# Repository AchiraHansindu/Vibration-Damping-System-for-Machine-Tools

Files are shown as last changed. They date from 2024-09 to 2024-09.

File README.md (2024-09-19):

# **Vibration Damping System for Machine Tools**

## Overview
This repository contains the design and implementation details of a Vibration Damping System developed for machine tools. The system is designed to significantly reduce mechanical vibrations, which can degrade performance and increase wear and tear on machinery.

## Project Scope

This project is done as a partial fulfillment for EN2160: Electronic Design Realization module in the Semester 4 curriculum in the Department of Electronic and Telecommunication Engineering at University of Moratuwa, Sri Lanka.

This project was aimed to design and develop an industry level solution. Accordingly, a hardware-software co-solution is developed including PCB, Enclosure, Software, and Firmware.

## Components
- **Data Acquisition System:** Utilizes accelerometers to measure vibrations and a microcontroller to process data.
- **Vibration Analysis Software:** MATLAB scripts and an app designed for processing and analyzing vibration data.
- **Spring and Damper System:** Custom designed spring and damper system to the specific vibration characteristics of the machinery.

<div align="center">
    Data Acquisition System
    <br>
    <em>Data Acquisition System</em>
</div>

<div align="center">
    Data Acquisition System
    <br>
    <em>Custom Built Shock Absorber</em>
</div>

## Features
- **Real-time Vibration Monitoring:** Leverages a MPU6050 accelerometer to monitor vibrations in real time.
- **FFT Analysis:** Implements Fast Fourier Transform (FFT) for detailed frequency analysis to calculate the desing parameters for the shock absorber system.
- **Shock Absorber Efficiency Measurement:** Compares vibration data before and after shock absorber implementation to evaluate efficiency.

## PCB Design
- **Tools & Software:** Designed with Altium Designer, our 2-layer PCB features the ATmega328P-AU microcontroller and CH340C Serial UART IC, ensuring robust performance and reliable communication.
- **Design Philosophy:** Special attention has been given to the routing of power lines to reduce voltage drops and ensure signal integrity.

<div align="center">
    Bare PCB
    <br>
    <em>Bare PCB</em>
</div>

<div align="center">
    Soldered PCB
    <br>
    <em>Soldered PCB</em>
</div>

PCB design files and schematics can be found [here](https://github.com/AchiraHansindu/Vibration-Damping-System-for-Machine-Tools/tree/main/PCB%20Files).

## Firmware Design
- **Microcontroller Programming:** The microcontroller in programmed in C++, using register level programming such as IO port manipulation, UART and I2C communication, sampling accelerometer reading with given sampling frequency.

The code can be found [here](https://github.com/AchiraHansindu/Vibration-Damping-System-for-Machine-Tools/tree/main/Microcontroller%20AVR%20code).

## Enclosure Design
- Comprises two parts; the Main Controller Unit and the Accelerometer Holding Part, both designed in SOLIDWORKS and produced via 3D printing.

<div align="center">
    Main Controller Unit
    <br>
    <em>Main Controller Unit</em>
</div>

<div align="center">
    Accelerometer Holding Part
    <br>
    <em>Accelerometer Holding Part</em>
</div>

Enclosure design files can be found [here](https://github.com/AchiraHansindu/Vibration-Damping-System-for-Machine-Tools/tree/main/Enclosure%20Design-SolidWorks).

## Software Design

### Front-End Software: UI for Data Acquisition System

The Front-End Software for the Vibration Data Acquisition System streamlines interaction between the DAQ device and the user. Developed using Python and PyQt5, the application features a user-friendly graphical interface for starting, stopping, and saving vibration data.

#### Key Features:
- **Initial Setup:** Users begin at a launch screen and proceed to select communication settings like COM port and baud rate.
- **Data Collection Controls:** Provides options to start and stop the recording and to save the captured data with user-defined settings.
- **Efficient Data Management:** After collection, data can be saved through a dialog that captures file details and confirms the save location.

This intuitive interface supports efficient data handling and simplifies the user's interaction with the system.

<div align="center">
    Screen for selecting the available COM port and baud rate.
    <br>
    <em>Screen for selecting the available COM port and baud rate.</em>
</div>

<div align="center">
    Screen for controlling data collection.
    <br>
    <em>Screen for controlling data collection.</em>
</div>

The code can be found [here](https://github.com/AchiraHansindu/Vibration-Damping-System-for-Machine-Tools/tree/main/UI%20for%20Data%20Acquisition%20System).

### MATLAB Application for Data Analysis

The MATLAB Application for Data Analysis enhances the vibration-damping system by providing detailed processing and visualization of vibrational data collected from machine tools. Developed to support engineers and researchers, this application includes multiple analytical tools and visualization methods.

#### Key Features:
- **Data Visualization:** Plots acceleration data along the X, Y, and Z axes, directly from CSV files generated by the DAQ system, providing immediate visual insight into the vibrational characteristics of the machine tools.
- **Frequency Spectrum Analysis:** Employs Fast Fourier Transform (FFT) to convert time-domain data into frequency-domain data, identifying dominant frequencies that are crucial for the subsequent design of effective vibration-damping solutions.
- **System Parameters Calculation:** Automatically extracts essential parameters such as natural frequency and damping ratio from FFT results. Users can further input mechanical properties like mass and piston diameter to compute critical damping characteristics, aiding in the precise design of the shock absorber.
- **Performance Comparison:** Facilitates loading and comparing vibration data before and after the implementation of damping solutions. 

This MATLAB application is a pivotal part of the software design, bridging data acquisition with actionable analysis, thus supporting both the design and evaluation stages of the vibration-damping system.

<div align="center">
    Window showing FFT for X, Y, and Z axes.
    <br>
    <em>Window showing FFT for X, Y, and Z axes.</em>
</div>

<div align="center">
    System parameters calculation window.
    <br>
    <em>System parameters calculation window.</em>
</div>

The code can be found [here](https://github.com/AchiraHansindu/Vibration-Damping-System-for-Machine-Tools/tree/main/MATLAB%20Application%20for%20Data%20Analysis).

## System Integration

The following images show some steps of system integration including wiring, assembling.

<div align="center">
    
    <br>
    <em></em>
</div>

<div align="center">
    
    <br>
    <em></em>
</div>

## Demonstration

To visually demonstrate the effectiveness of the Vibration Damping System, we have included videos and FFT analysis both before and after the implementation of the shock absorber.

### Videos

1. **Before Shock Absorber Implementation:**
   - This video showcases the system operating without the shock absorber, highlighting the initial vibration levels and rotation.

   https://github.com/user-attachments/assets/478091ad-a99a-40b5-b485-41ef5b800e22

2. **After Shock Absorber Implementation:**
   - This video demonstrates the system with the shock absorber installed, showing a significant reduction in vibrations and rotation.

   https://github.com/user-attachments/assets/1908306d-d9c9-451e-9375-d828b028359c

### FFT Analysis

- **FFT Before Implementation:**
  - The FFT analysis before implementing the shock absorber shows higher amplitude peaks at natural frequencies.

  <div align="center">
    FFT before implementing the damper
    <br>
    <em>FFT before implementing the damper</em>
</div>

- **FFT After Implementation:**
  - After the shock absorber installation, the FFT analysis displays a noticeable reduction in peak amplitudes.

  <div align="center">
    FFT after implementing the damper
    <br>
    <em>FFT after implementing the damper</em>
</div>

This side-by-side comparison not only validates the design but also provides concrete evidence of the system's performance improvements.

## Documents Related to the Project

For a deeper understanding of our Vibration Damping System, detailed documentation is available. Below are the links to various documents that cover all aspects of the project:

1. [Design Methodology Document](https://github.com/AchiraHansindu/Vibration-Damping-System-for-Machine-Tools/blob/main/Project%20Documents/Design_Methodology_Document_Vibration_Damping%20System_for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) 
2. [Comprehensive Design Document](https://github.com/AchiraHansindu/Vibration-Damping-System-for-Machine-Tools/blob/main/Project%20Documents/Design_Document_Vibration_Damping%20System_for_Machine_Too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) 

Feel free to explore these resources to gain a comprehensive understanding of the project's scope and execution.

## Team Members

- [Achira Hansindu](https://github.com/AchiraHansindu)
- [Sandaru Liyanaarachchi](https://github.com/Sandaru-Liyanaarachchi)

## Contributions

Contributions are welcome!

- **Bug Fixes:** If you find any bugs or issues, feel free to create an issue or submit a pull request.
-**Feature Enhancements:** If you have ideas for new features or improvements, don't hesitate to share them.

Feel free to reach out with any questions or suggestions!

## License

This project is licensed under the [MIT License](https://github.com/AchiraHansindu/Vibration-Damping-System-for-Machine-Tools/blob/main/LICENSE).

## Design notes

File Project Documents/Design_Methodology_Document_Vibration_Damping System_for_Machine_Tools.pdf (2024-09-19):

# Department of Electronic and Telecommunication Engineering University of Moratuwa

# EN2160- Electronic Design Realization

# Design Methodology Document


# Vibration Damping System for Machine Tools

# Group K (29)

210204R Hansindu K.A.A.

210341H Liyanaarachchi L.A.S.

## Contents

1 Introduction | 5
2 Review Progress | 6
2.1.2 | Vibration Damping Control of Robot Arm Intended for Service
2.1.5 | Hybrid Damper with Tunable Particle Impact Damping and
3 Identification Of Stake Holders | 12
4 Observe Users | 15

1

5 Need List | 19
6 Stimulate Ideas | 21
7 Conceptual Design | 23

2

8 Evaluation of Conceptual Design | 33
9 Schematic Design | 37
10 PCB Design | 44
11 SolidWorks Design | 47

3

References | 56

4

## 1 Introduction

The Design Methodology Document for the Vibration Damping System for Machine Tools was created following the Cambridge EDC Inclusive Design Methodology. This document provides a comprehensive overview of the project’s development, focusing on designing a data acquisition system for vibrational data and a spring and damper system to enhance the performance and reliability of machine tools. The primary objectives of this project are to minimize vibrations that can affect the precision and longevity of machine tools and to provide a robust data acquisition framework for continuous monitoring and analysis.
The methodology employed ensures that the design process is thorough, inclusive, and user-centered, incorporating feedback from a wide range of stakeholders including engineers, developers, manufacturers, and end-users. This approach not only improves the design’s functionality but also ensures its practical applicability in real-world scenarios.
Key aspects of the design process include:
- Review of Existing Solutions: Analyzing current industry practices and academic research to understand the state-of-the-art in vibration damping systems.
- Stakeholder Engagement: Identifying and involving key stakeholders to gather requirements and ensure the design meets their needs.
- User Observation and Feedback: Studying how different users interact with machine tools and identifying their needs and pain points.
- Concept Development: Generating multiple design concepts and evaluating them against established criteria to select the most effective solution.
- Detailed Design and Prototyping: Creating detailed schematics and prototypes, followed by rigorous testing to validate the design.

The document is structured to provide a clear and detailed account of each phase of the project, ensuring transparency and facilitating future enhancements. This systematic and inclusive approach ensures the development of a reliable, efficient, and user-friendly vibration damping system that can significantly improve the operational efficiency and precision of machine tools.

5

## 2 Review Progress

A thorough analysis of the current advancements in vibration-damping systems for machine tools was conducted, drawing insights from industry practices, academic research, and existing commercial solutions. This review provided a solid foundation for our project’s objectives and methodology.

### 2.1 Academic Research

Research papers highlight the importance of accurately identifying the natural frequencies of machine tools to design effective damping systems. Techniques using accelerometers and signal processing algorithms have been widely studied.

### 2.1.1 Analysis of Vibration Damping in Machine Tools

Description: This study provides a detailed analysis of energy dissipation mechanisms in machine tools, incorporating frictional forces, control loops, and modal damping into numerical models.

Key Findings: Highlights the significance of integrating these mechanisms for accurate dynamic behavior prediction, crucial for optimizing material removal and minimizing oscillations.

Reference: Bianchi, G. et al., 2014. ”Analysis of Vibration Damping in Machine Tools,” Procedia CIRP.

Link: Analysis of Vibration Damping in Machine Tools (https://www.researchgate.net/publication/275230904_Analysis_of_Vibration_Damping_in_Machine_Tools)

### 2.1.2 Vibration Damping Control of Robot Arm Intended for Service

Application in Human Environment

Description: This study investigates the vibration-damping control of
an anthropomorphic robot arm designed for service applications, focusing
on improving safety and performance during physical interactions with humans and the environment.

Key Findings: The research demonstrates that by using torque measurement in each joint and tactile area recognition, the proposed vibration damping control significantly reduces oscillations in heavily loaded joints. This is achieved through acceleration signal feedback and a lead controller, enhancing the robot’s smooth continuous motion and ensuring safer interactions with humans.
Reference: Tsetserukou, D., Kawakami, N., & Tachi, S. (2008). ”Vibration Damping Control of Robot Arm Intended for Service Application in Human Environment,” 2008 8th IEEE-RAS International Conference on Humanoid Robots (Humanoids 2008). DOI: 10.1109/ICHR.2008.4756002

Link: Vibration damping control of robot arm intended for service application in the human environment (https://www.researchgate.net/publication/224373517_Vibration_damping_control_of_robot_arm_intended_for_service_application_in_human_environment)

6

### 2.1.3 Active Vibration Control for a CNC Milling Machine

Description: Explores adaptive vibration control methods for CNC milling machines, focusing on improving surface finish, reducing tool wear, and compensating for structural vibrations under high-speed machining conditions.

Key Findings: The active vibration control system uses sensors and adaptive controllers to measure and mitigate vibrations, resulting in improved machining accuracy and surface quality. The study demonstrated significant vibration reduction and enhanced stability in CNC milling operations.

Reference: Ford, D.G., Myers, A., Haase, F., Lockwood, S., & Longstaff, A.P. (2013). ”Active Vibration Control for a CNC Milling Machine,” Proceedings of the Institution of Mechanical Engineers, Part C: Journal of Mechanical Engineering Science. DOI: 10.1177/0954406213484224

Link: Active vibration control for a CNC milling machine (https://www.academia.edu/56290445/Active_vibration_control_for_a_CNC_milling_machine)

### 2.1.4 Active Vibration Damping with Magnetic Actuators

Description: Explores the use of magnetic actuators for active damping of machine tools, focusing on reducing chatter and improving machining stability.

Key Findings: Effective in suppressing vibrations, enhancing tool performance, increasing dynamic stiffness, and significantly improving chatterfree material removal rates.

Reference: Chen, F., Hanifzadegan, M., Altintas, Y., & Lu, X. (2015). ”Active Damping of Boring Bar Vibration With a Magnetic Actuator,” IEEE/ASME Transactions on Mechatronics, 20(6), 1-12. DOI:

Link: Active Damping of Boring Bar Vibration With a Magnetic Actuator (https://www.researchgate.net/publication/276383735_Active_Damping_of_Boring_Bar_Vibration_With_a_Magnetic_Actuator)

### 2.1.5 Hybrid Damper with Tunable Particle Impact Damping and Coulomb

Friction

Description: This study examines a hybrid damper combining a particle impact damper (PID) and a Coulomb friction damper (FD). It highlights the advantages of both damping technologies, aiming to improve the damping capacity of the PID and FD. The damper is theoretically modeled and experimentally tested on a single-degree-of-freedom (SDOF) structure.

Key Findings: The proposed hybrid damper effectively reduces the maximum vibration amplitude by 66% and 43% compared to using the FD and PID only, respectively. It is also effective over a wide range of excitation

7

frequencies and does not require an optimally tuned natural frequency and damping, unlike traditional tuned mass dampers (TMDs).

Reference: Akbar, M.A., Wong, W.-O., & Rustighi, E. (2023). ”A Hybrid Damper with Tunable Particle Impact Damping and Coulomb Friction,” Machines, 11(5), 545. DOI: 10.3390/machines11050545

Link: Hybrid Damper with Tunable Particle Impact Damping and Coulomb Friction (https://www.mdpi.com/2075-1702/11/5/545)

### 2.2 Industry Developments

Industry advancements in vibration-damping systems for machine tools have led to the development of both active and passive solutions designed to enhance machining precision and tool life. These products demonstrate significant advancements in reducing vibrations, thereby enhancing machining performance and tool longevity.

### 2.2.1 Sandvik Coromant - Silent Tools™ Turning Adapters

Description: The Silent Tools™ turning adapters by Sandvik Coromant feature an advanced internal damping mechanism designed to reduce vibrations during machining operations with long overhangs. The damping unit consists of a heavy mass supported by rubber spring elements and an oil-filled cavity, which enhances the damping effect.

Key Features: Enhanced damping mechanism, improved surface finish, increased tool life, and efficient performance in long overhang operations.

Applications: Ideal for internal turning operations with extended tool lengths.
Link: Silent Tools™ for turning (https://www.sandvik.coromant.com/en-us/tools/turning-tools/internal-turning-tools/silent-tools-turning)

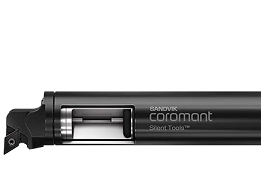
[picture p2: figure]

Figure 1: Silent Tools™ cylindrical turning adaptors

8

### 2.2.2 Big Daishowa - Smart Damper

Description: The Smart Damper by Big Daishowa integrates a damping mechanism close to the cutting edge, which significantly reduces vibrations in deep boring applications. The system is designed for both fine and rough boring operations.

Key Features: High efficiency in deep hole finish boring, improved surface finish, and extended tool life.

Applications: Ideal for boring operations requiring high precision and minimal vibration.

Link: Damping Tools (https://www.bigkaiser.eu/en/products/damping-tools.html)

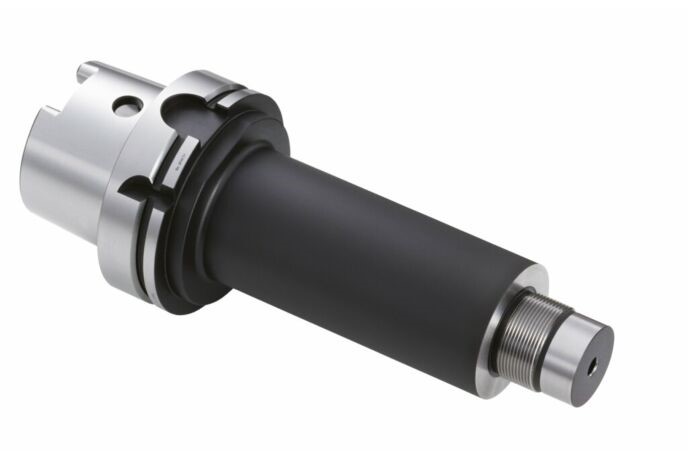
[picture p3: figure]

Figure 2: Smart Damper Basic Holders for Mills HSK-A

### 2.2.3 Seco Tools - Steadyline® Vibration Damping System

Description: The Steadyline® system by Seco Tools is designed for high rigidity and stability during extreme cutting conditions. It employs a dynamic passive damping system within the holder body, where a damping mass counteracts flexural vibrations.

Key Features: Available in various bar sizes (6xD, 8xD, 10xD), features coolant supply channels, and quick mounting and setting procedures.

Applications: Suitable for roughing and finishing operations with long overhang tools, providing high metal-removal rates and smooth surface finishes.
Link: Seco expands Steadyline® vibration damping system with boring bars (https://www.secotools.com/article/20850)

9

Figure 3: Seco expands Steadyline® vibration damping system with boring bars

### 2.2.4 Makino - ADVANTiGE Active Damping System

Description: The ADVANTiGE system by Makino adjusts frictional forces based on low-frequency vibration sensing to avoid chatter and cutter damage in real-time. This active damping system significantly enhances machining performance by enabling deeper cuts and higher metal-removal rates.

Key Features: Real-time vibration suppression, reduced tool wear, and improved machining accuracy.

Applications: Particularly effective in titanium machining and other high-stress cutting operations.

Link: Makino - ADVANTiGE Active Damping System (https://www.timachining.com/)

### 2.3 Summary of Findings

- Real-Time Adaptability: Active systems using sensors and control algorithms are highly effective in dynamically adjusting to vibrations, offering significant improvements in machining accuracy and tool longevity.
- Hybrid Solutions: Combining different damping mechanisms (e.g., particle impact and spring-damper systems) provides a versatile solution that can address a broader frequency range.
- Cost-Effectiveness: While active systems offer precise control, passive systems are more cost-effective and easier to implement, making them suitable for smaller workshops with budget constraints.

### 2.4 Progress

Upon receiving approval for the project, we began by planning the architecture of the Vibration Damping System (VDS) for machine tools, which features two primary components: the damping mechanism and the control module. The damping mechanism is designed to reduce vibrations passively. The control module serves as the command center, monitoring vibration levels.
The initial stage of the project focuses on designing and simulating the circuit schematics and mechanical layouts to ensure the VDS will achieve its targeted goals. Significant progress has been made in drafting the schematics for both the damping

10 mechanism and control module circuits. While the design of the control module is advancing smoothly, we have encountered challenges with the damping mechanism due to the need for precise tuning and component selection to maximize efficiency and minimize space requirements.
To overcome these obstacles, we are continuously reviewing and refining our designs. This involves experimenting with various strategies, such as exploring alternative components, adjusting layout configurations, and employing advanced signal processing algorithms for vibration detection and control. We are also integrating feedback from experts and conducting peer reviews to address potential issues proactively.
Throughout the design phase, we regularly review our progress to ensure alignment with project timelines and goals. This iterative process allows us to make necessary adjustments and improvements to the schematics. Once the circuit designs are complete and validated through rigorous testing, we will transition to implementing the circuits on prototype boards. These prototypes will undergo comprehensive laboratory testing to ensure they meet performance, safety, and reliability standards. Successful validation of the prototypes will pave the way for developing printed circuit boards (PCBs) using surface-mounted electronic components, enhancing the compactness and suitability of the system for industrial applications. Our ongoing review process includes testing various use-case scenarios and monitoring the interaction between the VDS components to ensure optimal performance.
As we finalize the PCB designs, our focus will shift to designing and manufacturing an enclosure that meets industry standards and provides adequate protection for the VDS hardware. Additionally, we aim to develop a user-friendly interface that allows operators to monitor and control the system easily. This interface will provide real-time data on vibration levels and system performance, enabling proactive maintenance and adjustment of the damping mechanism.
By continuously refining our approach and incorporating user feedback, we strive to deliver a top-tier, reliable, and efficient vibration-damping system for machine tools, enhancing machining precision and tool longevity.

11

## 3 Identification Of Stake Holders

Creating a stakeholder map for the Vibration Damping System for Machine Tools involves identifying and categorizing the various stakeholders involved in the development, implementation, and use of the system. This categorization helps in understanding their roles, interests, and influence on the project, ensuring effective engagement and management strategies are in place to optimize project outcomes.

### 3.1 Stakeholders Identified

### 3.1.1 Engineers and Developers

- Description: Responsible for designing and developing the vibration-damping system. This includes mechanical engineers, electrical engineers, and software developers.
- Interest/Influence: High interest, high influence.

### 3.1.2 Manufacturers of Machine Tools

- Description: Companies involved in producing machine tools that could benefit from vibration-damping technology. Their input is crucial for integration and compatibility.
- Interest/Influence: High interest, high influence.

### 3.1.3 End Users

- Description: Operators who will use the machine tools equipped with the vibration damping technology. Their feedback on usability and effectiveness is valuable.
- Interest/Influence: High interest, medium influence.

### 3.1.4 Maintenance Technicians

- Description: Individuals responsible for maintaining and servicing the vibration-damping system and the machine tools it’s integrated with.
- Interest/Influence: Medium interest, medium influence.

### 3.1.5 Quality Control Managers

- Description: Personnel ensuring that the vibration-damping system meets quality standards and performance expectations.
- Interest/Influence: Medium interest, medium influence.

12

### 3.1.6 Safety Regulators

- Description: Government agencies or industry organizations responsible for ensuring the safety standards of industrial machinery, including vibration-damping systems.
- Interest/Influence: High interest, high influence.

### 3.1.7 Investors

- Description: Individuals or entities financially invested in the development and success of the vibration-damping system project.
- Interest/Influence: High interest, high influence.

### 3.1.8 Suppliers

- Description: Companies providing components or materials necessary for the production of the vibration-damping system.
- Interest/Influence: Medium interest, medium influence.

### 3.1.9 Training Instructors

- Description: Personnel responsible for training end-users on operating and maintaining the vibration-damping system effectively.
- Interest/Influence: Medium interest, low influence.

### 3.1.10 Competitors

- Description: Other companies developing similar vibration-damping technologies or alternative solutions.
- Interest/Influence: High interest, high influence.

### 3.1.11 Industry Associations

- Description: Groups representing the interests of manufacturers, engineers, or users within the machine tool industry.
- Interest/Influence: Medium interest, medium influence.

### 3.1.12 Research Institutions

- Description: Universities or research centers conducting studies on vibration-damping technology and its applications.
- Interest/Influence: High interest, medium influence.

13

### 3.2 Stakeholder Map

The stakeholder map diagram visually represents the various stakeholders involved in the Vibration Damping System for Machine Tools project. It categorizes stakeholders based on their levels of interest and influence, facilitating effective engagement and management strategies.

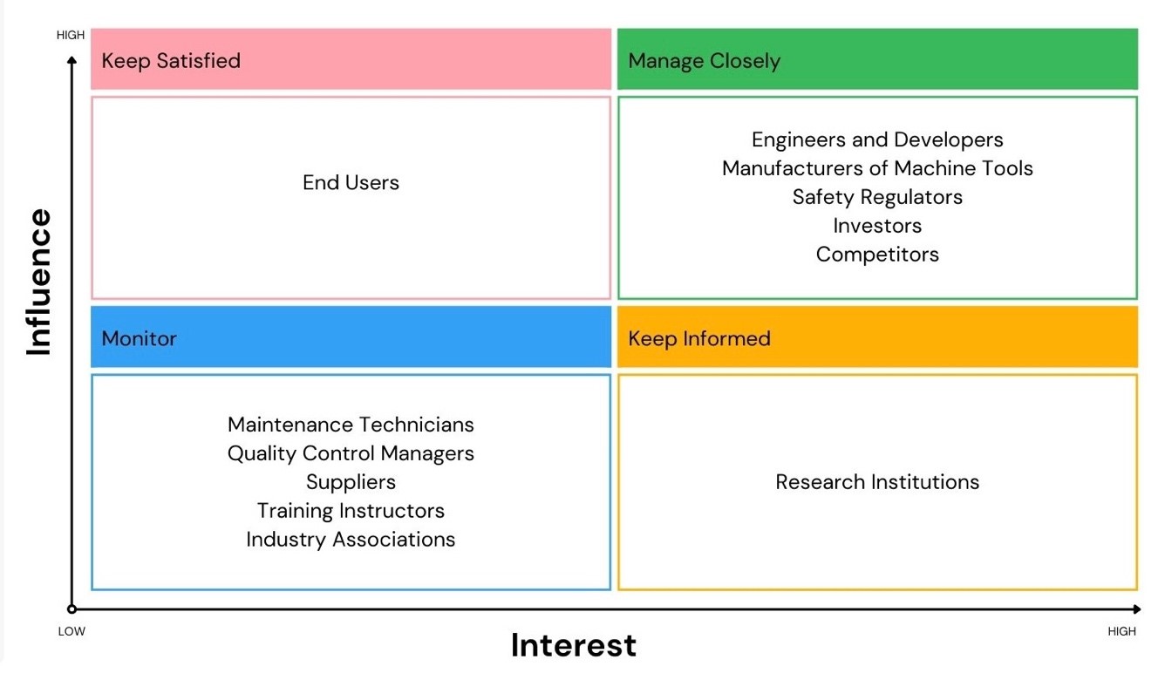
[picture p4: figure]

Figure 4: Stakeholder Map

This systematic classification ensures thorough engagement with key stakeholders and maintains regular communication channels with those deemed most critical. By aligning stakeholder engagement strategies with their respective levels of interest and influence, project stakeholders can be effectively managed to optimize project outcomes.

Competitors Examples

- Sandvik Coromant
- Seco Tools
- BIG Daishowa

By incorporating these stakeholder management strategies, we aim to ensure that all relevant parties are engaged appropriately throughout the project life cycle, thereby maximizing the potential for successful outcomes.

14

## 4 Observe Users

The objective of this section is to identify how different types of users interact with the Vibration Damping System (VDS) for machine tools, ascertain their needs and challenges, and evaluate the system’s performance in meeting these requirements. This information is vital for guiding design enhancements that cater to a diverse range of user scenarios and needs.

### 4.1 User Profiles

Observing various categories of users and their specific interaction with the VDS provides insights into how the system can be optimized to meet their needs:

### 4.1.1 Machine Tool Operators

Operators who work directly with machine tools equipped with Vibration Damping Systems. Their primary focus is on achieving precise machining outcomes, minimizing tool wear, and ensuring smooth operations.

- How operators adjust the VDS settings during different machining operations, ease of use, and their feedback on vibration reduction effectiveness.

### 4.1.2 Maintenance Technicians

Individuals are responsible for the upkeep and maintenance of the machine tools and the VDS. They need the system to be reliable and easy to troubleshoot.

- Frequency of maintenance required, common issues faced, and effectiveness of the VDS in reducing wear and tear.

### 4.1.3 Quality Control Managers

Personnel ensure that the VDS meets quality standards and enhances the machining process. They focus on the consistency and reliability of the vibration damping.

- Impact of the VDS on product quality, ease of monitoring system performance, and integration with quality control processes.

### 4.1.4 Production Managers

Managers overseeing the overall production process, who are interested in the efficiency and productivity gains provided by the VDS.

- Improvements in production speed and output, reduction in downtime due to machine vibrations, and overall cost savings.

15

### 4.2 User Needs and Requirements

Through observation, the following user needs and requirements should be identified and analyzed:

### 4.2.1 Scalability

The VDS should be adaptable to various machine types and operational scales. This includes the ability to handle different levels of vibration and integrate with a wide range of machine tools.

- Flexibility in system configuration, ease of scaling the solution up or down, and adaptability to different operational conditions.

### 4.2.2 Safety and Reliability

Users across all sectors prioritize a system that provides robust safety features and consistent reliability. This includes protection against system failures and ensuring operational safety.

- Frequency of system failures, effectiveness of safety features, and user confidence in the system’s reliability.

### 4.2.3 Monitoring and Reporting

The VDS should provide real-time monitoring of key metrics such as vibration levels, system status, and performance data. It should offer users easy access to this data, possibly through user-friendly interfaces and data visualization tools.

- User interactions with monitoring tools, ease of accessing and interpreting data, and the usefulness of the provided information in decision-making.

### 4.2.4 Ease of Use

The user experience with the VDS should be intuitive and straightforward. This involves examining the system’s installation, configuration, and daily operation for different types of users.

- Complexity of system setup and configuration, user training requirements, and overall user satisfaction with the interface.

### 4.3 User Feedback and Pain Points

Gathering user feedback and identifying pain points is crucial to improving the Vibration Damping System.

16

### 4.3.1 Complexity

Observing users’ ability to understand and operate the VDS, focusing on whether they find the system complex and if any particular areas require simplification.

- Specific components or processes users struggle with, suggestions for simplifying operations, and overall user comfort with the system.

### 4.3.2 Integration

Evaluate the VDS’s compatibility and ease of integration with other systems, such as machine control systems, quality control tools, and data management systems.

- Challenges in integrating the VDS with existing systems, compatibility issues, and user satisfaction with the integration process.

### 4.3.3 Support and Documentation

Investigate the level of support provided, including documentation quality and customer service responsiveness. Proper support and comprehensive documentation play a significant role in the user’s experience.

- Availability and usefulness of support resources, quality of documentation, and user satisfaction with customer service.

### 4.4 Real-World Use Cases

Analyzing real-world applications and use cases provides practical insights.

### 4.4.1 Application in High-Precision Machining

Assess the VDS’s performance and adaptability in maintaining precision during high-speed machining operations.

- Improvements in precision, reduction in tool wear, and overall system stability during complex machining tasks.

### 4.4.2 Application in Heavy-Duty Industrial Settings

Evaluate how the VDS handles the specific requirements of heavy-duty industrial applications, including the ability to manage high levels of vibration.

- Effectiveness in reducing vibrations in heavy-duty operations, impact on machine longevity, and improvements in operational safety.

17

### 4.4.3 Application in Small-Scale Workshops

Examine how the VDS meets the needs of smaller workshops, ensuring ease of use and affordability while maintaining performance and safety.

- User satisfaction in small-scale settings, cost-benefit analysis, and any specific challenges faced by smaller operations.

By systematically observing users across these various categories and their interactions with the VDS, the design team can derive actionable insights for enhancing the system’s functionality, ease of use, and reliability across a broad range of applications. This will enable the creation of a robust and versatile VDS that meets the diverse needs of its users.

18

## 5 Need List

To ensure the Vibration Damping System (VDS) for machine tools meets user needs effectively, the following user requirements have been identified. These requirements are derived from observations and interactions with various user groups, including machine operators, maintenance technicians, quality control managers, and production managers.

### 5.1 Ease of Installation

- User Requirement: The VDS should be designed with a focus on user accessibility, featuring a streamlined installation process that demands minimal technical expertise or specialized tools.
- Implementation: Comprehensive installation guides should provide clear stepby-step instructions, helping users navigate the setup process efficiently and accurately, reducing the chance of installation errors and ensuring a successful initial configuration.

### 5.2 User-Friendly Operation

- User Requirement: The VDS should offer a highly intuitive interface with user-centric controls, allowing operators to navigate the system effortlessly and efficiently.
- Implementation: A centralized monitoring system should provide real-time access to essential metrics, such as vibration levels, system status, and performance data, empowering users to make informed decisions and maintain optimal system performance.

### 5.3 Extensive System Visibility

- User Requirement: The VDS should offer in-depth visibility into system status and performance, granting users access to detailed data and analytics regarding the health and condition of the machine tools.
- Implementation: Such comprehensive insight facilitates strategic decision-making, enabling users to manage system performance, forecast maintenance needs, and optimize overall operational strategies.

19

### 5.4 Reduced Maintenance Requirements

- User Requirement : Routine maintenance tasks, such as firmware updates and system diagnostics, should be straightforward and manageable even for users with limited technical expertise.
- Implementation: The VDS should include self-diagnostic capabilities that enable continuous monitoring and analysis of system performance, proactively identifying and addressing potential issues to ensure smooth, uninterrupted operation.

### 5.5 Streamlined System Management

- User Requirement: The VDS should integrate advanced functionalities that simplify system management, such as adaptive damping algorithms and efficient vibration control methods, to promote the longevity and sustained performance of the machine tools.
- Implementation: Its intelligent features should contribute to enhanced machine efficiency, reducing wear and extending the machine’s usable life, which in turn supports overall productivity goals.

### 5.6 Proactive Issue Resolution

- User Requirement: The VDS should incorporate sophisticated monitoring and diagnostic tools that proactively identify potential issues and anomalies within the machine tools.
- Implementation: By addressing issues before they become critical, the VDS should minimize system downtime, increase safety, and enhance operational efficiency, leading to greater overall reliability and user satisfaction.

By addressing these user requirements, the VDS for machine tools can be optimized to meet the diverse needs of its users, ensuring a robust and user-friendly system that enhances overall productivity and reliability.

20

## 6 Stimulate Ideas

To develop innovative solutions for the Vibration Damping System (VDS) for machine tools, we employed several idea stimulation techniques. These methods foster creativity, collaboration, and thorough exploration of potential solutions.

### 6.1 Idea Stimulation Techniques Used

### 6.1.1 Research and Benchmarking

- Approach: Conducting extensive research on existing vibration damping technologies and benchmarking against industry standards.
- Benefits: Identifies current best practices, uncovers gaps in the market, and provides a foundation for developing advanced solutions.

### 6.1.2 Peer Discussion

- Approach: Engaging in regular discussions with peers and experts to share knowledge, experiences, and insights related to vibration damping technology.
- Benefits: Promotes knowledge exchange, sparks new ideas, and offers diverse perspectives on potential solutions.

### 6.1.3 Mind Mapping

- Approach: Utilizing mind mapping tools to visually organize thoughts and ideas related to the VDS project.
- Benefits: Helps in identifying connections between different concepts, encourages structured thinking, and facilitates brainstorming sessions.

### 6.1.4 Brainstorming

- Approach: Conducting structured brainstorming sessions to generate a wide range of ideas and solutions for the Vibration Damping System.
- Benefits: Encourages free thinking, allows for the rapid generation of ideas, and promotes team collaboration. Rules such as ”no idea is a bad idea” and ”build on others’ ideas” are followed.

### 6.1.5 Conceptual Design Creation

- Approach: Developing multiple conceptual designs to explore various approaches to vibration damping.
- Benefits: Visualizes potential solutions, allows for comparison of different designs, and facilitates the evaluation of their feasibility and effectiveness.

21

### 6.2 Process Overview

### 6.2.1 Conduct Comprehensive Research

Gather information on existing technologies, materials, and methodologies related to vibration damping.

### 6.2.2 Initiate Discussions

Regularly scheduled meetings with team members and experts to discuss the project and share insights.

### 6.2.3 Create Mind Maps

Use mind mapping to organize ideas, identify key concepts, and establish relationships between different elements of the Vibration Damping System project.

### 6.2.4 Brainstorm Sessions

Host brainstorming sessions where all team members contribute ideas without criticism. Document all suggestions for further analysis.

### 6.2.5 Develop Conceptual Designs

Translate the most promising ideas into conceptual designs. Create sketches and models to visualize each concept.

### 6.2.6 Evaluate Designs

Assess each conceptual design for feasibility, cost, effectiveness, and potential impact. Select the best ideas for further development.
By integrating these techniques, we can ensure a thorough exploration of potential solutions, leading to innovative and effective designs for the VDS.

22

## 7 Conceptual Design

In the course of our collaborative efforts, both within our core team and with our wider project stakeholders, we have developed several conceptual designs for our product. These designs meticulously detail both the aesthetic exterior and the internal functional architecture, showcasing how each component interacts within the system. We have developed four design sketches accompanied by functional block diagrams to illustrate our proposed concepts.

### 7.1 Concept - 1

### 7.1.1 Overview

Concept 1 presents a portable DAQ device with a Wi-Fi connection, USB charging, and an OLED display, eliminating the need for a wired connection and enabling easy data transfer for vibration analysis over WIFI using a Wi-Fi-compatible MCU.

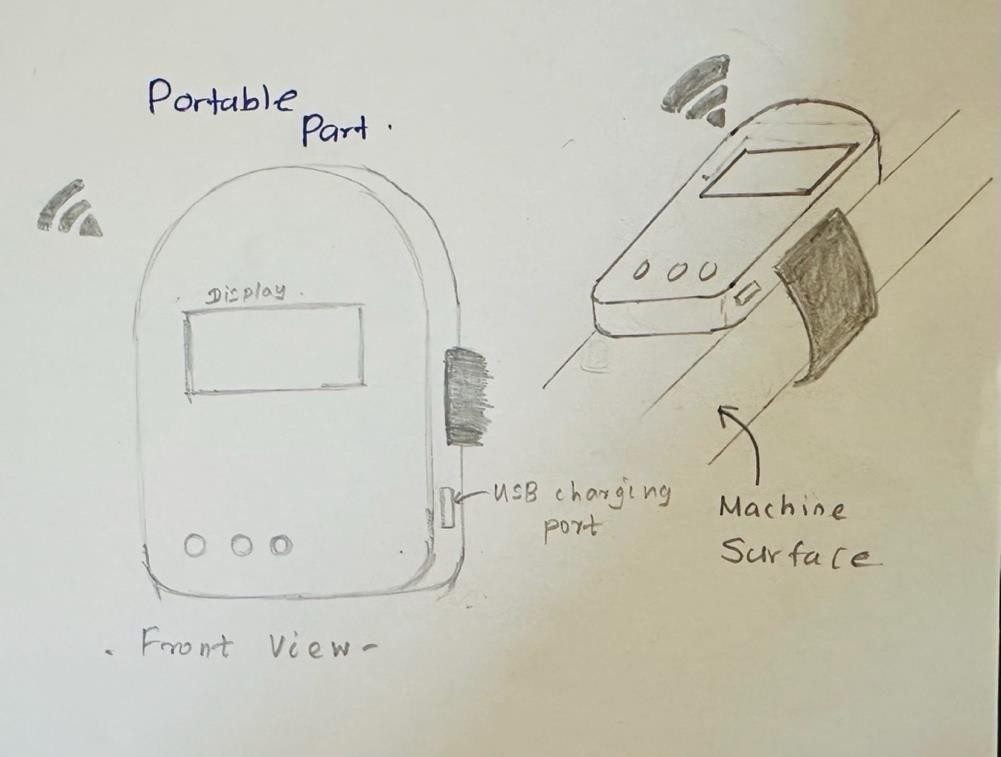
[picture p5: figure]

Figure 5: Conceptual Design 1

Figure 6: Functional Block Diagram 1

23

### 7.1.2 Key Features

- Portable and Compact: The device is designed to be easily attached to machine surfaces and carried around as needed.
- Wireless Communication: Equipped with a Wi-Fi-compatible microcontroller unit (MCU), the device communicates wirelessly with a computer, facilitating real-time data transfer and analysis.
- Display and Interface: An OLED display provides real-time feedback and operational status, enhancing user interaction.
- Power Supply: The device includes a rechargeable battery with a USB charging port, ensuring continuous operation without the need for frequent battery replacements.

### 7.1.3 Benefits

- Ease of Use: The portable nature and wireless communication eliminate the hassle of dealing with cables, making it user-friendly and easy to deploy in various settings.
- Real-Time Monitoring: Allows for real-time data acquisition and analysis, enabling prompt responses to vibration issues.
- Versatility: Suitable for a wide range of machine tools and environments due to its compact and flexible design.

24

### 7.2 Concept - 2

### 7.2.1 Overview

Concept 2 integrates a wired connection with separate sections for data acquisition and display, incorporating a dedicated power supply. This design favors a direct cabled power source and computational division, foregoing Wi-Fi connectivity and USB charging for potentially enhanced stability and processing power.

Figure 7: Conceptual Design 2

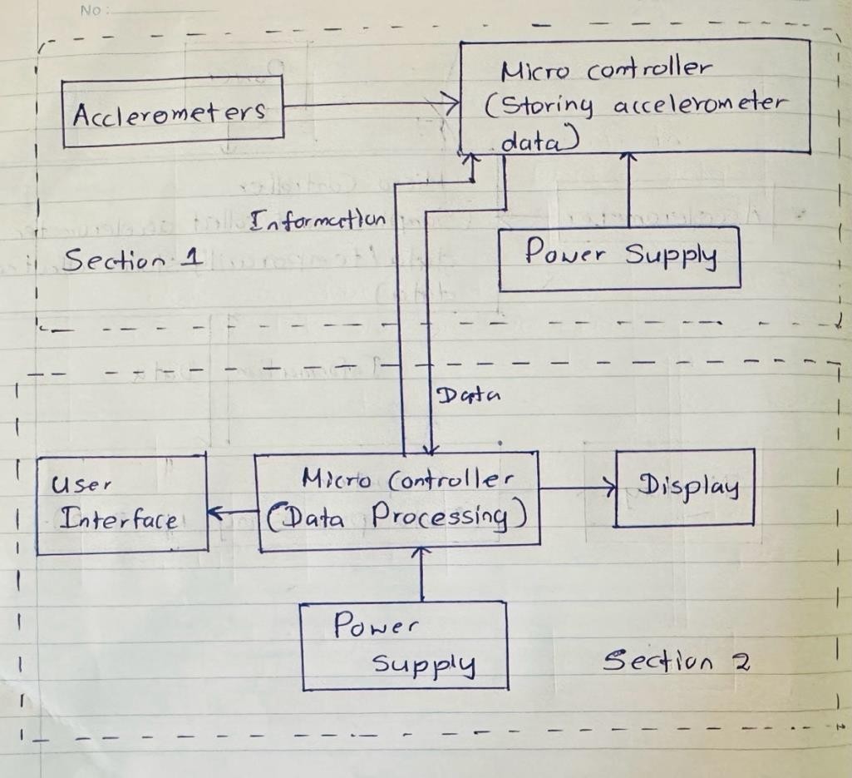
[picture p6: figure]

Figure 8: Functional Block Diagram 2

25

### 7.2.2 Key Features

- Sectional Design: The system is divided into two sections - one for data acquisition and another for data processing and display.
- Wired Communication: Ensures stable and reliable data transfer between sections.
- Dedicated Power Supply: Provides continuous and consistent power to both sections, reducing the risk of power interruptions.

### 7.2.3 Benefits

- Enhanced Stability: Wired connections provide more stable and reliable data transfer compared to wireless systems.
- Robust Design: Suitable for environments where wireless communication might be unreliable or undesirable.

26

### 7.3 Concept - 3

### 7.3.1 Overview

This design utilizes a wired accelerometer and omits the digital display, focusing on direct data acquisition and processing through a lightweight cable connection to a computer. The emphasis is on a simple, robust system that prioritizes data accuracy and processing efficiency.

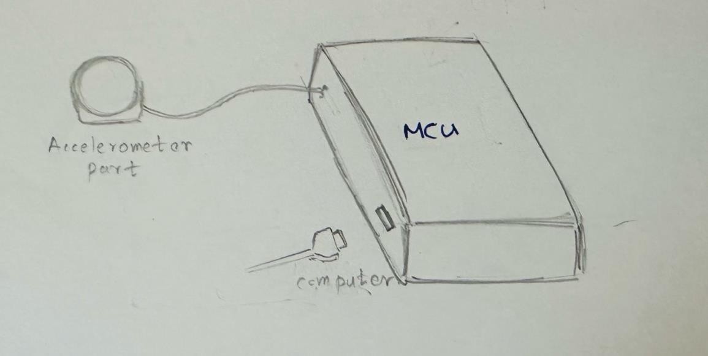
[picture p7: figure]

Figure 9: Conceptual Design 3

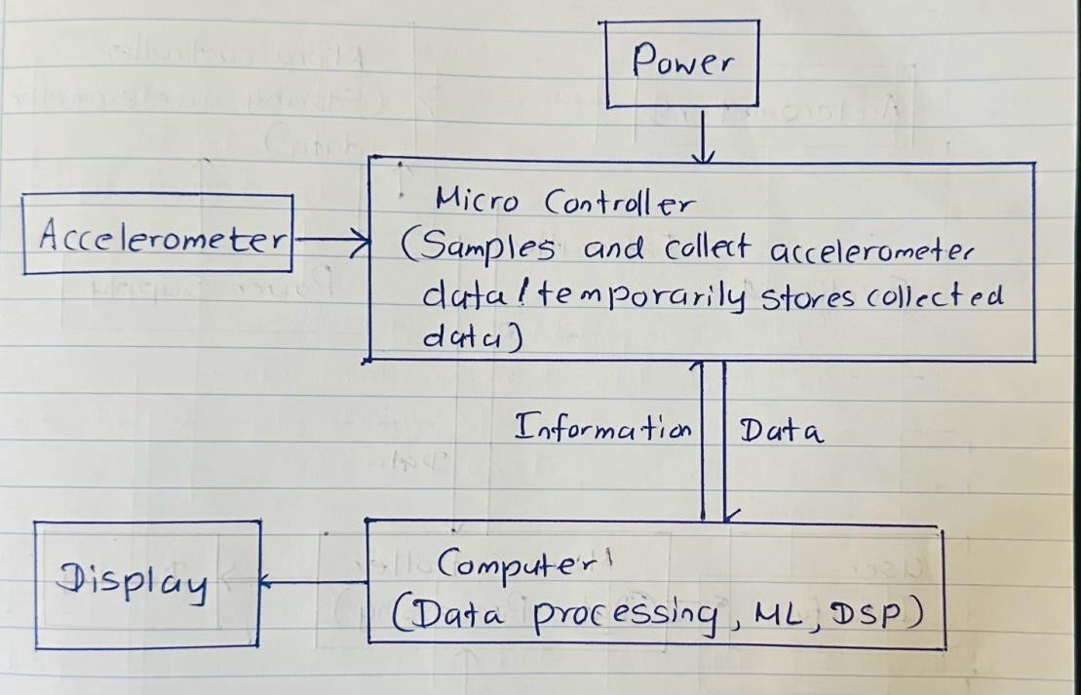
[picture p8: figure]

Figure 10: Functional Block Diagram 3

27

### 7.3.2 Key Features

- Wired Accelerometer Connection: Ensures reliable and consistent data transfer from the accelerometer to the microcontroller.
- Direct Data Processing: Data is directly sent to a computer for processing, leveraging advanced algorithms for analysis.
- Simplified Design: By omitting a digital display, the system reduces complexity and potential points of failure.

### 7.3.3 Benefits

- Enhanced Data Accuracy: The wired connection minimizes data loss and latency, ensuring high-precision vibration measurement.
- Increased Processing Power: Offloading data processing to a computer allows for more sophisticated analysis using machine learning and digital signal processing (DSP) techniques.
- Robust and Reliable: Simplified hardware design enhances reliability and ease of maintenance.

28

### 7.4 Concept - 4

### 7.4.1 Overview

Concept 4 introduces multiple portable DAQ units with Wi-Fi capability, eliminating wired constraints for a scalable, precise vibration signal acquisition system communicating wirelessly with a central computer.

Figure 11: Conceptual Design 4

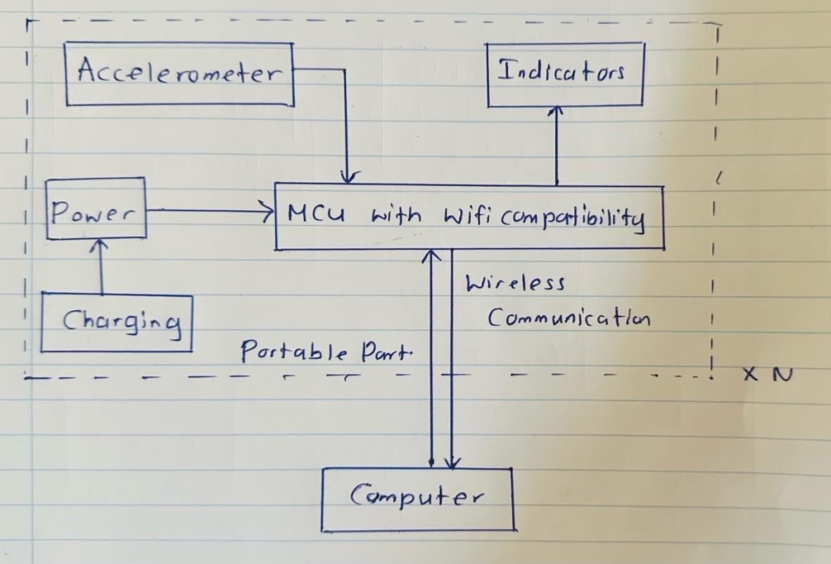
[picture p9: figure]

Figure 12: Functional Block Diagram 4

29

### 7.4.2 Key Features

- Multiple Portable Units: Each unit can be attached to different parts of the machine to gather comprehensive vibration data.
- Wi-Fi Communication: Equipped with Wi-Fi-compatible microcontroller units (MCUs), the devices communicate wirelessly with a central computer, allowing for real-time data transfer and analysis.
- Indicators: Each unit features indicators to provide visual feedback on operational status.
- Power Supply and Charging: Includes an integrated power supply with charging capabilities, ensuring continuous operation.

### 7.4.3 Benefits

- Scalability: The system can easily scale by adding more units, allowing for detailed vibration monitoring across large or complex machinery.
- Flexibility: Wireless communication eliminates the need for extensive cabling, simplifying installation and setup.
- Precision: Multiple units provide a comprehensive view of vibration patterns, enhancing the accuracy of the analysis.

30

### 7.5 Mechanical Damper System

### 7.5.1 Overview

This design features a mechanical damper system utilizing a spring and damper mechanism. The design is intended to absorb and dissipate vibrations through mechanical means, enhancing the stability and precision of machine tools.

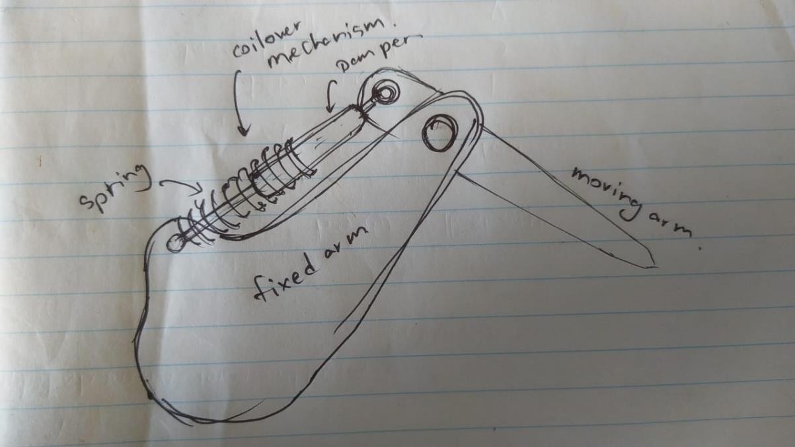
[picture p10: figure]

Figure 13: Damper

### 7.5.2 Key Features

- Spring and Damper Mechanism: Utilizes a coilover mechanism that includes a spring and a damper to reduce vibrations effectively.
- Fixed and Moving Arms: The system comprises a fixed arm and a moving arm, allowing for dynamic absorption of vibrations during machine operation.
- Mechanical Design: Focuses on a purely mechanical approach, eliminating the need for electronic components.

### 7.5.3 Benefits

- Simplicity and Reliability: The mechanical nature of the system ensures durability and requires minimal maintenance.
- Effective Vibration Reduction: The spring and damper combination provides a robust solution for damping vibrations, improving the overall performance of machine tools.
- Cost-Effective: Without the need for electronic components, the system is economical to produce and maintain.

31

### 7.6 Conclusion

By developing and comparing these conceptual designs, we aim to identify the most effective and feasible solution for implementing a Vibration Damping System that meets the diverse needs of our users and stakeholders. Each design offers unique advantages and caters to different operational requirements, ensuring a comprehensive approach to vibration management in machine tools. The next steps involve detailed evaluation and prototyping to determine the optimal design for practical application.

32

## 8 Evaluation of Conceptual Design

To determine the most effective and feasible solution for implementing the Vibration Damping System (VDS), we evaluated each conceptual design based on two primary criteria: Enclosure Design Criteria and Functional Block Diagram Criteria. This evaluation helps ensure that the selected design meets both the practical requirements and the functional needs of the system.

### 8.1 Evaluation Criteria

### 8.1.1 Enclosure Design Criteria:

1. Functionality: How well does the design support the main functionalities?
2. Aesthetics: How much eye-catching and overall appeal of the user?
3. Precision: How accurate is the gathered data?
4. Assembly and Serviceability: How easily is the assembly and disassembly done?
5. Simplicity
6. Durability: How well does the design withstand impacts and environmental conditions?

### 8.1.2 Functional Block Diagram Criteria:

1. Functionality: How well does the circuit design meet functional requirements?
2. User Experience: How intuitive and user-friendly is the interaction?
3. Manufacturing Feasibility: Evaluate the feasibility of manufacturing the design.
4. Cost: Evaluate the overall cost-effectiveness of the provided functionality.
5. Performance: Evaluate the signal quality, resolution, and bandwidth range.
6. Power Efficiency: How effectively does the device manage power consumption?

33

### 8.2 Complete Comparison

34

### 8.3 Selected Conceptual Design

In our product, we prioritize computational power due to our use of MATLAB for data processing. While developing an interactive user-friendly interface is desirable, it has been deemed lower priority compared to ensuring core functionality. Additionally, the decision to use a wired connection over Wi-Fi is influenced by concerns about Wi-Fi’s error rates, which could affect the precision of the vibration data collected. Our selected design is Conceptual Design 3, which utilizes a wired accelerometer system, emphasizing direct data acquisition and processing through a lightweight cable connection to a computer. This design is cost-effective, easy to use, and meets our need for high computational power and precision.

Figure 14: Conceptual Design 3

Figure 15: Functional Block Diagram 3

35

Conceptual Design 3 is selected as the final design for several compelling reasons:

- Computational Power: This design provides enhanced computational power necessary for processing vibration data using MATLAB. The direct connection to a computer allows leveraging advanced data processing algorithms, machine learning, and digital signal processing (DSP) techniques, which are crucial for accurate and sophisticated vibration analysis.
- Data Accuracy and Precision: The wired accelerometer connection ensures reliable and consistent data transfer, minimizing data loss and latency. This is critical for achieving high-precision vibration measurement, essential for diagnosing and mitigating vibration issues in machine tools.
- Cost-Effectiveness: The simplified hardware design of Design 3 is economical to produce and maintain. By omitting the digital display and focusing on core functionality, the design reduces production costs without compromising performance.
- Ease of Use: The straightforward design and direct data processing reduce the complexity of the system, making it user-friendly. Maintenance and troubleshooting are simpler due to fewer components and connections.
- Stability and Reliability: The wired connection provides a stable and robust solution, reducing the risk of data transmission errors that can occur with wireless systems. This enhances the overall reliability of the system, ensuring consistent performance in industrial environments.

Overall, Conceptual Design 3 stands out as the optimal choice for a Vibration Damping System for machine tools due to its combination of computational power, data accuracy, cost-effectiveness, ease of use, stability, and flexibility. Its robust design makes it well-suited for various industrial applications, ensuring precise vibration measurement and analysis, ultimately contributing to improved productivity and operational efficiency.

36

## 9 Schematic Design

Designing electronic circuits is essential to ensure the seamless operation of our data acquisition (DAQ) system. The schematic design of our Vibration Damping System (VDS) is meticulously crafted to ensure proper functionality and integration of various components. The schematics provide a detailed view of the connections between different electronic elements such as resistors, capacitors, transistors, and integrated circuits. This section will highlight the key components and their configurations.

### 9.1 Key Components and Their Configurations

### 9.1.1 Sensor Input Circuit

The sensor input circuit is designed to interface with accelerometers, capturing vibration data. The main components are:

- Accelerometer: Captures vibration data and sends it to the microcontroller.

This circuit is crucial for accurate data acquisition, providing the raw input needed for analysis.

### 9.1.2 Microcontroller Circuit (ATmega328P)

The microcontroller circuit, built around the ATmega328P, serves as the central unit for data processing and communication. Key features include:

- ATmega328P Microcontroller: Handles data acquisition, processing, and communication tasks.
- Crystal Oscillator: Provides the clock signal for the microcontroller, ensuring precise timing operations.
- Decoupling Capacitors: Placed close to the IC to filter out noise and provide a stable power supply to the microcontroller.

This setup is designed for efficient data handling and communication, forming the core of the DAQ system.

### 9.1.3 USB Port Circuit (CH340C)

The USB port circuit incorporates the CH340C IC, facilitating communication between the DAQ system and a computer. This circuit includes:

- CH340C USB-to-Serial Converter: Enables seamless data transfer via USB.
- Capacitors: Two 0.1µF capacitors for noise filtering.

37

- LED Indicators: Provide visual feedback on the status of the data transfer.

This circuit ensures easy and reliable communication with external devices, enhancing the system’s usability.

### 9.1.4 Power Supply Circuit (LM7805)

The power supply circuit features the LM7805 linear voltage regulator, providing a stable 5V supply essential for our microcontroller and other components. The design includes:

- LM7805 Voltage Regulator: Ensures a steady 5V output.
- Capacitors: Two 10µF capacitors are used for input and output filtering to stabilize the voltage and reduce noise.

This configuration offers a reliable power source, crucial for maintaining consistent performance across the DAQ system.

### 9.2 Component List

The major components required for the circuit design are:

- ATmega328P Microcontroller
- LM7805 Voltage Regulator
- CH340C USB-to-Serial Converter
- Capacitors (10µF, 0.1µF)
- Crystal Oscillator (e.g., 16MHz)
- LEDs (for status indication)
- External Power Source (e.g., 12V DC)
- Resistors
- Programming Header
- Pin Connectors (for sensor connections)

These components collectively ensure the robust operation of the DAQ system, enabling precise vibration data acquisition and reliable communication with external devices.

### 9.3 Schematic Diagram

38

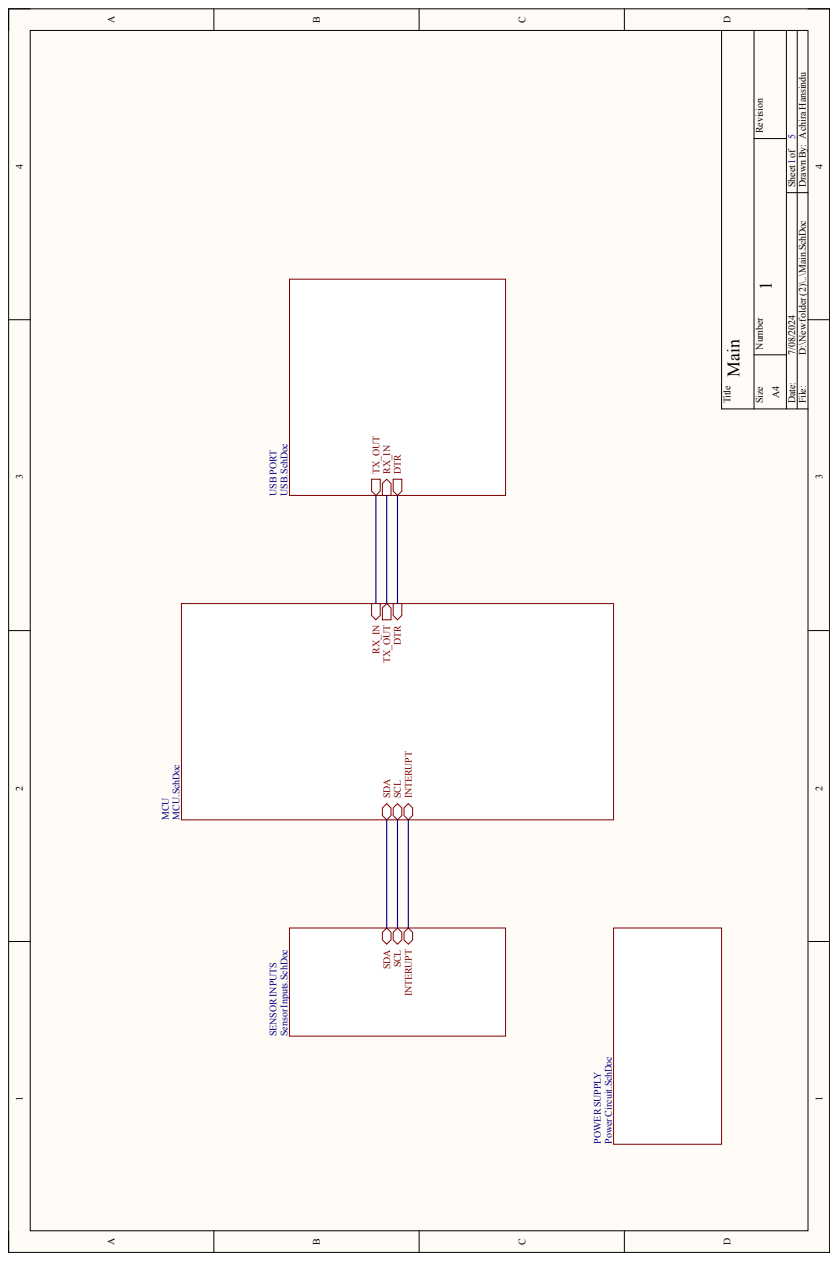
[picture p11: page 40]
Title; SDA SCL; INTERUPT; TX_OUT DTR; MCU; MCU.SchDoc; POWERSUPPLY; SDA; SCL; SENSORINPUTS; SensorInputs.SchDoc; TX_OUT RX_IN DTR; USBPORT; USB.SchDoc; Main; Achira Hansindu

Number Revision Size

Date: 7/08/2024 Sheet of

File: D:\New folder (2)\..\Main.SchDoc Drawn By:

Power Circuit.SchDoc

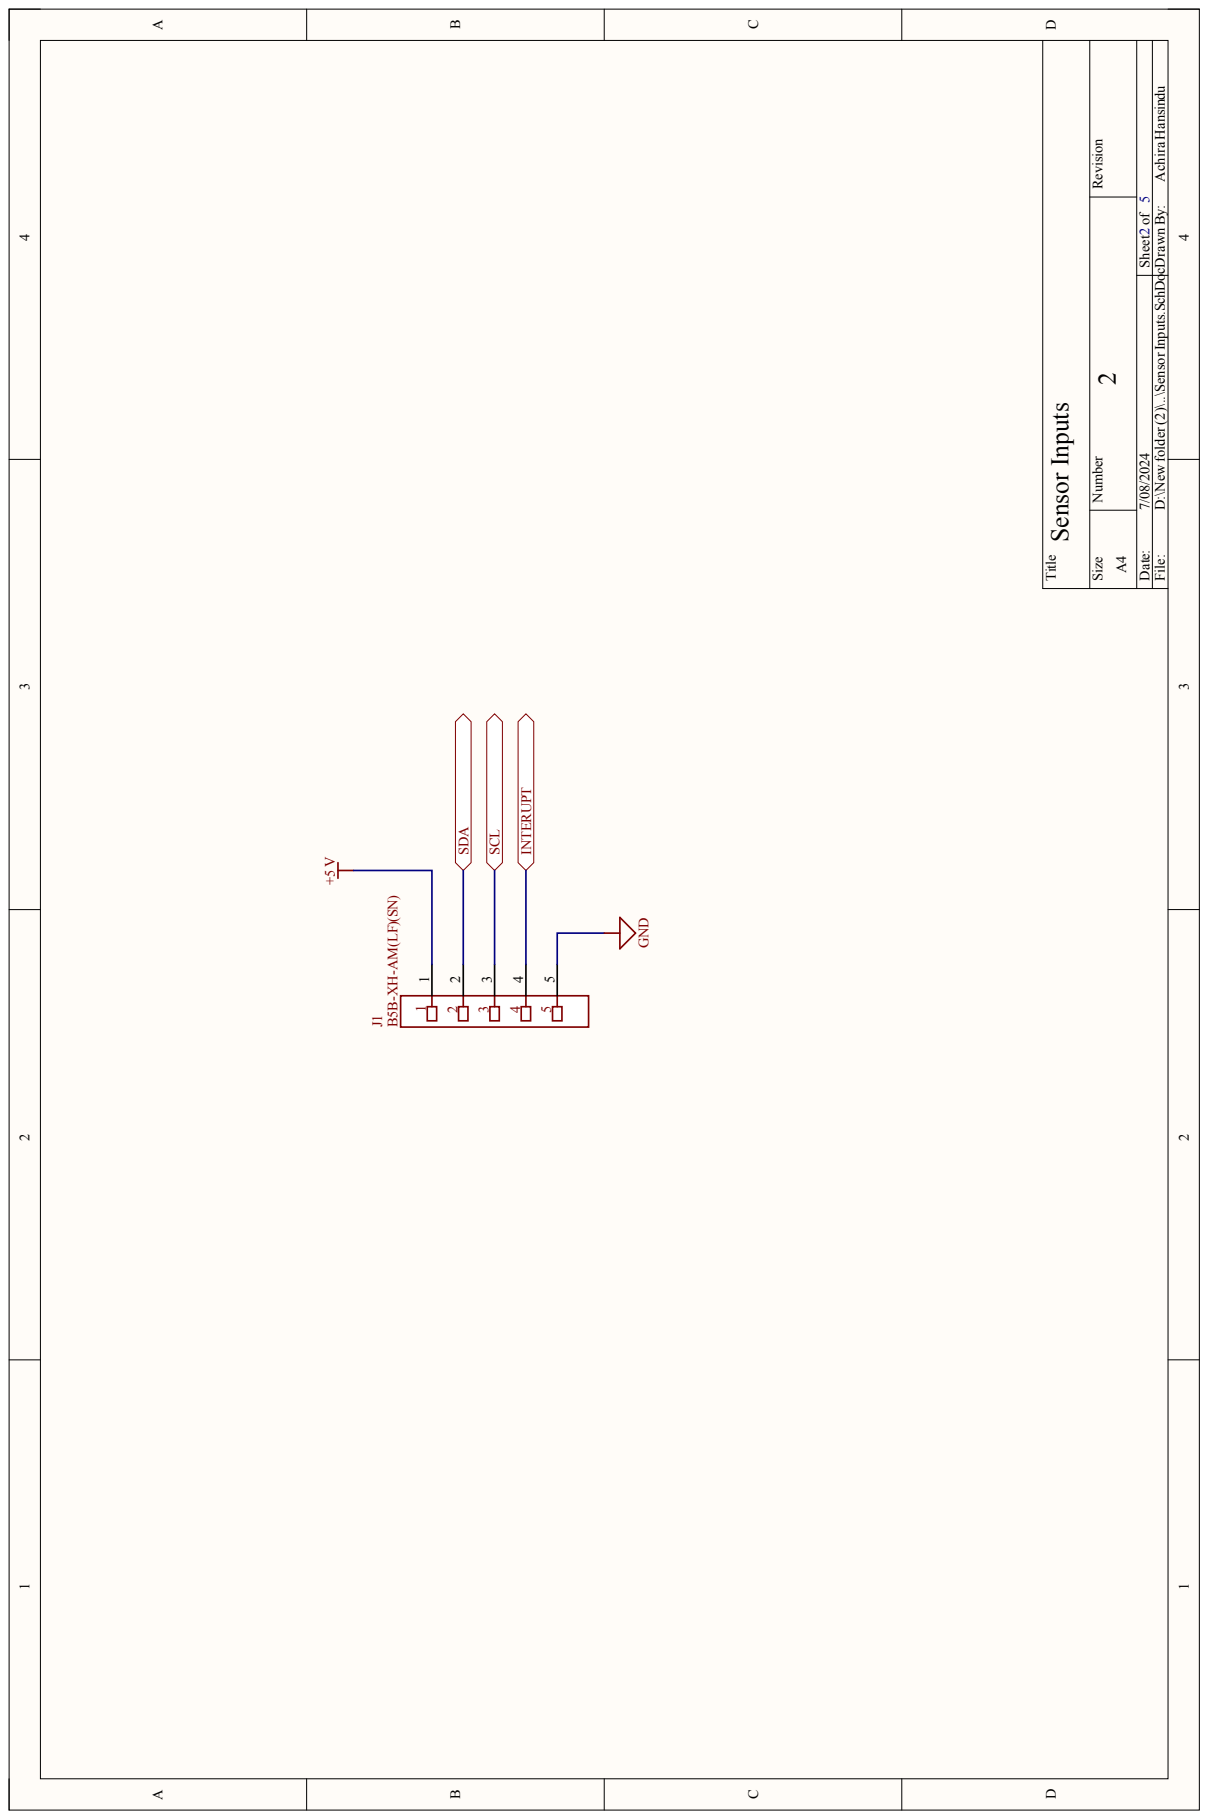
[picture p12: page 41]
Title; SDA; SCL; INTERUPT; Sensor Inputs; Achira Hansindu; GND; PIJ101; PIJ102; PIJ103; PIJ104; PIJ105; COJ1; PIJ102 POSDA; PIJ103 POSCL; POSDA; POINTERUPT

Number Revision Size

Date: 7/08/2024 Sheet of

File: D:\New folder (2)\..\SensorInputs.SchDocDrawn By:

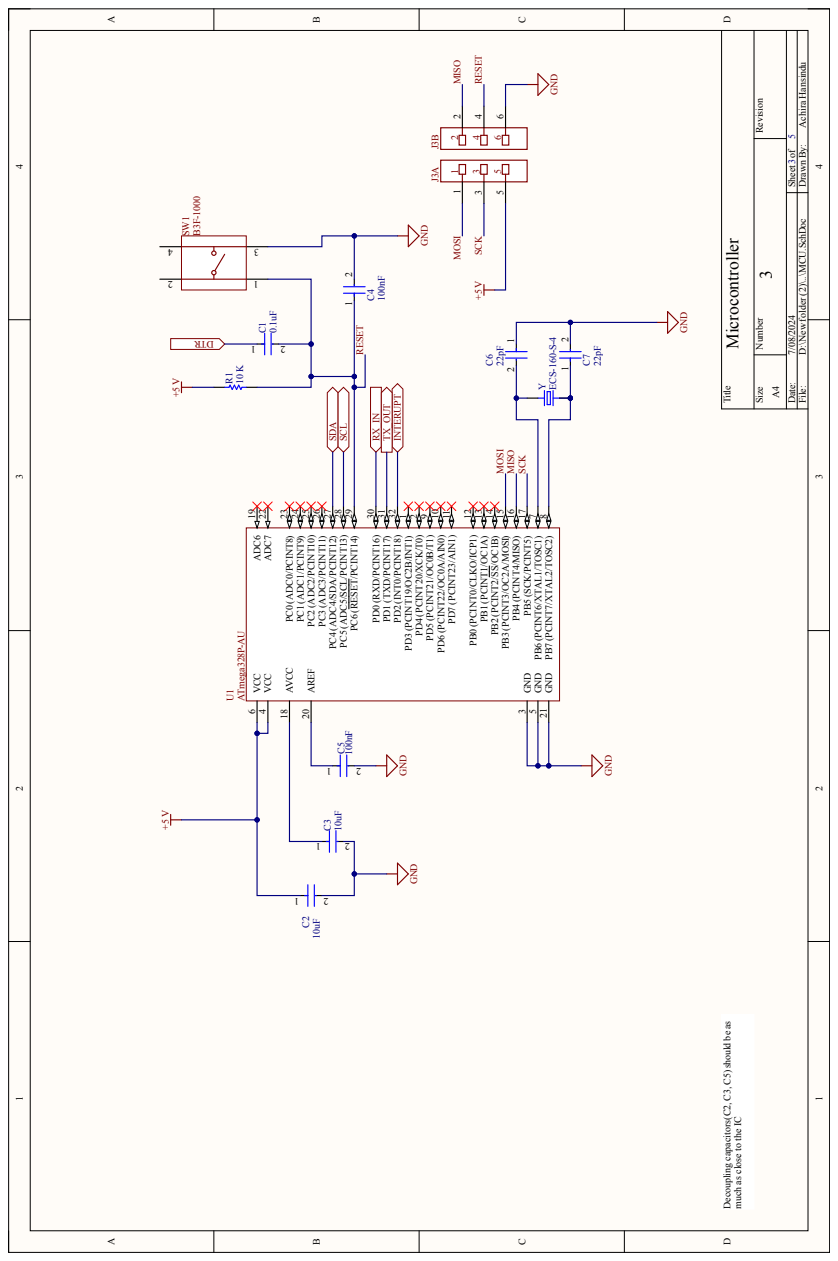
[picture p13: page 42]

File: D:\New folder (2)\..\MCU.SchDoc Drawn By:

Microcontroller Decoupling capacitors(C2,C3,C5)should be as much as close to the IC

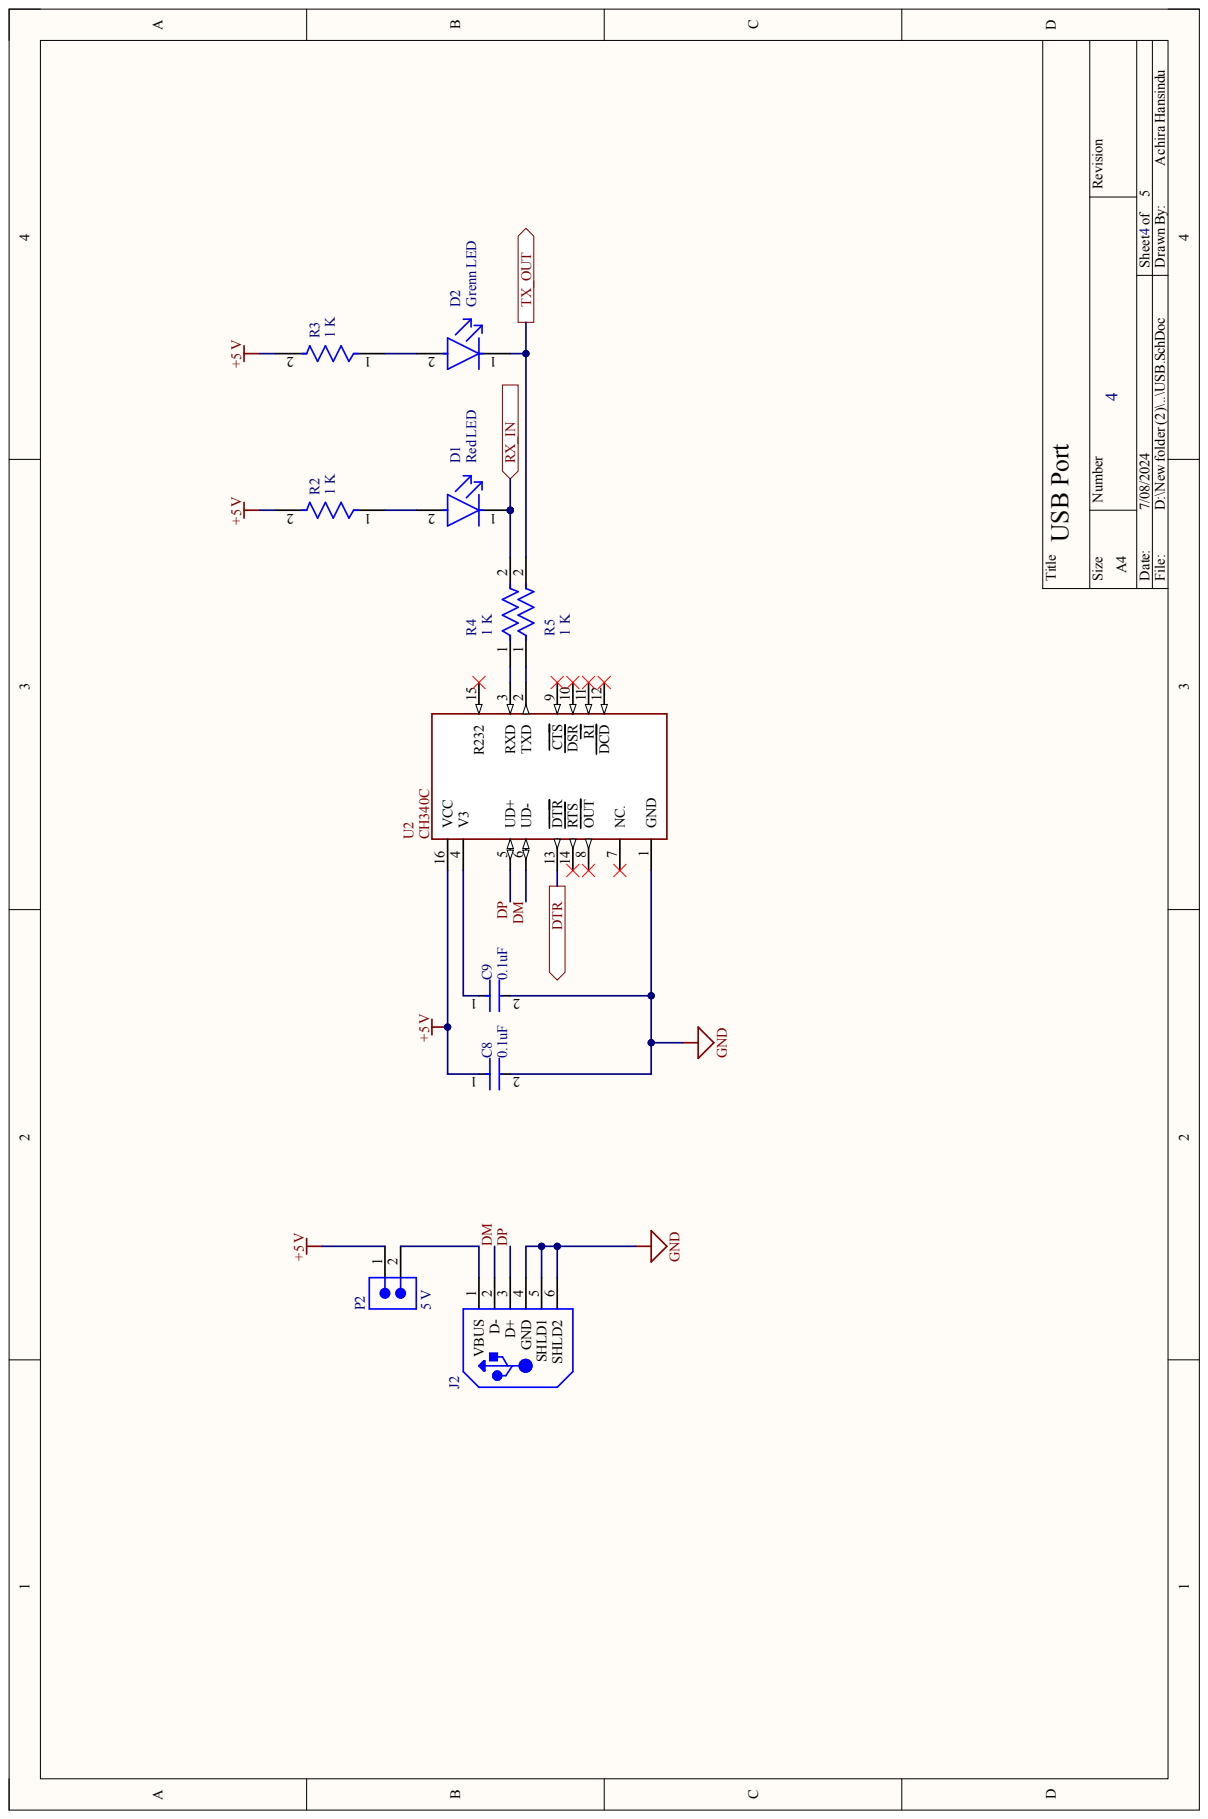
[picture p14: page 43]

File: D:\New folder (2)\..\USB.SchDoc Drawn By:

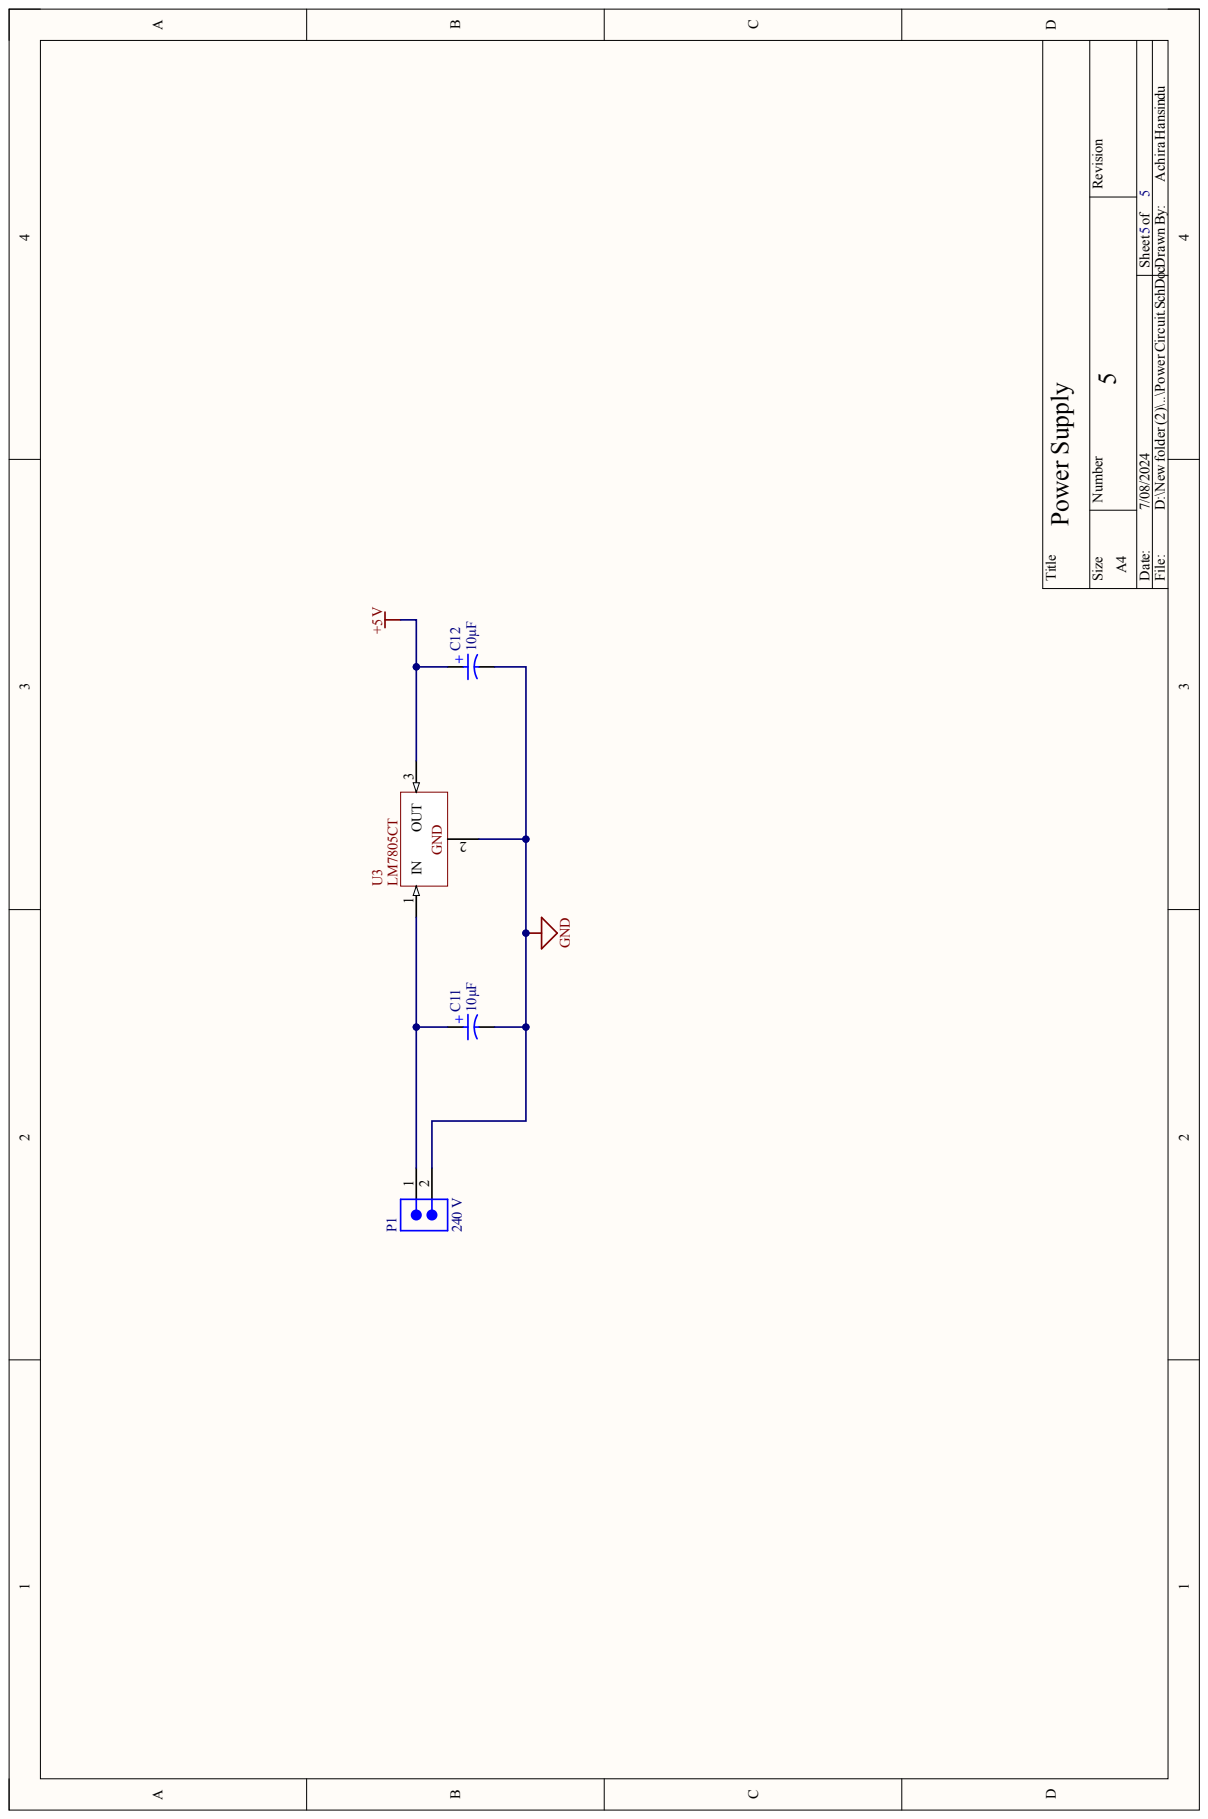
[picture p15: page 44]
Title; Power Supply; GND; Achira Hansindu

Number Revision Size

Date: 7/08/2024 Sheet of

File: D:\New folder (2)\..\Power Circuit.SchDocDrawn By:

## 10 PCB Design

The PCB layout integrates all schematic designs onto a single board, ensuring optimal component placement and efficient signal routing. Our design process prioritizes robustness, reliability, and ease of integration. The PCB layout has been meticulously crafted to meet the high standards required for effective vibration damping systems.

### 10.1 Key Considerations

### 10.1.1 Traces

Adequate width traces are used for power paths to minimize voltage drop and support the current requirements of the components.

Signal traces are routed to minimize interference and maintain signal integrity, ensuring reliable communication between components.

### 10.1.2 Component Placement

Components are positioned strategically to minimize trace lengths and optimize signal paths.

Critical components such as the microcontroller and ICs are placed centrally to enhance stability and performance.

### 10.1.3 Thermal Management

Heat dissipation for components such as the LM7805 voltage regulator and the microcontroller is managed through proper placement and the addition of heat sinks where necessary.

This ensures components operate within safe temperature ranges, enhancing reliability and lifespan.

44

### 10.2 PCB Layout Details

10.2.1 2D View

The 2D view of the PCB provides a detailed layout of component placement and trace routing, showcasing the systematic organization of all elements. It highlights the efficient use of board space and the logical arrangement of components to support functional and mechanical requirements.

Figure 16: 2D View

10.2.2 3D View

The 3D view offers a comprehensive visualization of the assembled PCB, including component heights and spatial relationships. This perspective aids in ensuring that all components fit within the designated enclosure and meet the design specifications for physical integration.

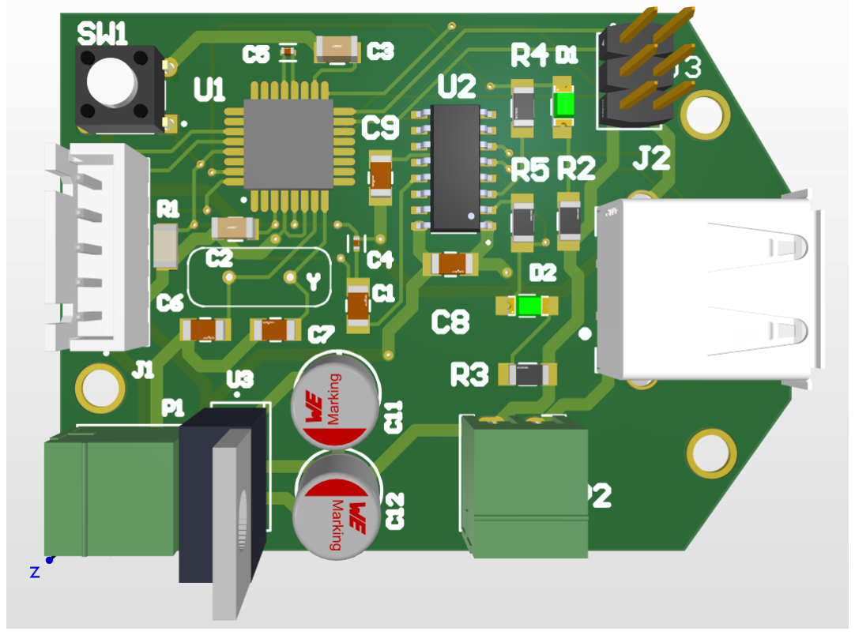
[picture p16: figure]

Figure 17: 3D View

45

### 10.3 Conclusion

The final PCB design encapsulates the critical aspects of our schematics into a cohesive, reliable, and efficient layout. By adhering to best practices in PCB design, we ensure that the vibration-damping system meets its performance objectives while maintaining ease of manufacturing and assembly. This comprehensive design approach facilitates seamless integration into machine tools, offering a robust solution for vibration damping.
By focusing on these design principles, we have developed a PCB layout that is not only effective in its functionality but also optimized for production and operational reliability.

46

## 11 SolidWorks Design

Our SolidWorks design consists of two primary components: the Main Controller Unit and the Accelerometer Holding Part. Both designs are moldable and have been meticulously created to ensure functionality and ease of manufacturing. Below are the details and design trees for both components:

### 11.1 Main Controller Unit

The Main Controller Unit part is designed to house the main microcontroller and associated electronic components. The design includes a base and a lid, both moldable for efficient manufacturing.

### 11.1.1 Main Controller Unit Base

- The base is designed to hold the microcontroller securely.
- It includes mounting points for the PCB and provisions for connectors and other components.
- Features like cable entry points are incorporated for optimal functionality.

### 11.1.2 Main Controller Unit Lid

- The lid is designed to enclose the Main Controller Unit securely.
- It includes features for easy attachment to the base, such as screw holes.
- The lid design ensures that all components are protected while allowing access for maintenance.

### 11.1.3 Assembly

- The assembly of the Main Controller Unit involves aligning the base and the lid and securing them together.
- The design ensures that the assembly process is straightforward, with clear alignment features to avoid any misfits.

47

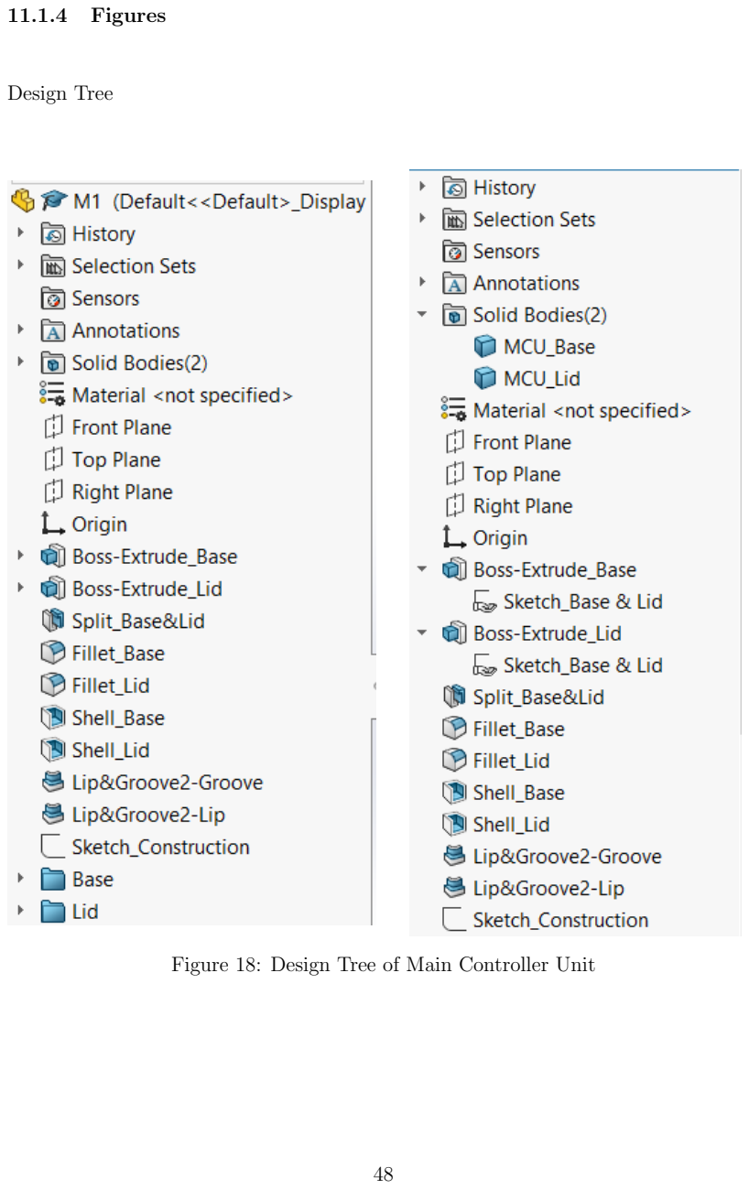
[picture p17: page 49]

### 11.1.4 Figures

Design Tree

Figure 18: Design Tree of Main Controller Unit

48

Figure 19: Design Tree of Main Controller Unit Base

Figure 20: Design Tree of Main Controller Unit Lid

49

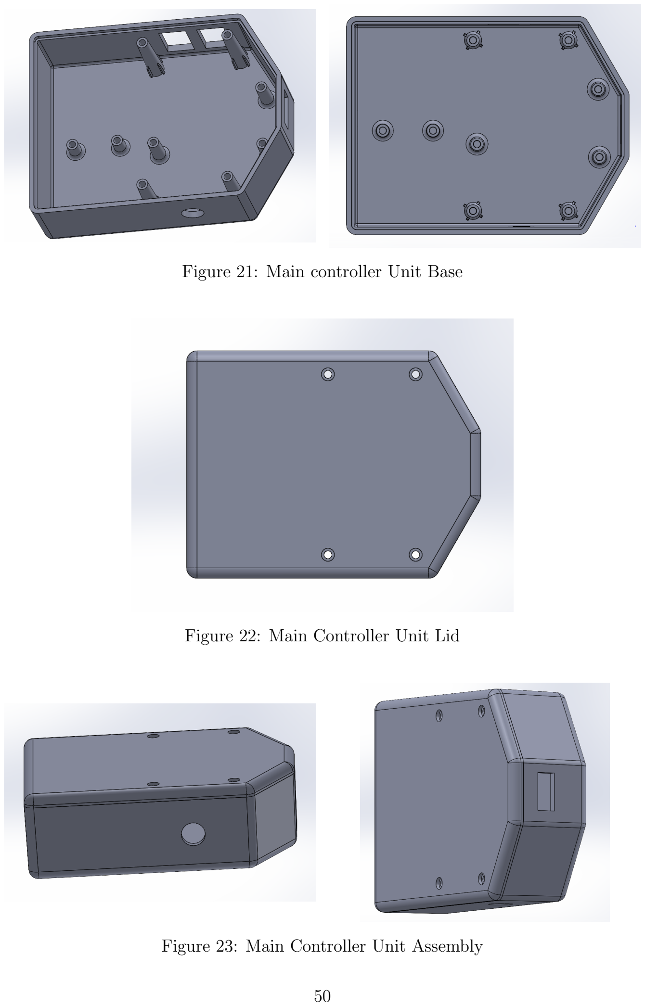
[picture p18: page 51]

Figure 21: Main controller Unit Base

Figure 22: Main Controller Unit Lid

Figure 23: Main Controller Unit Assembly

50

### 11.2 Accelerometer Holding Part

The Accelerometer Holding Part is designed to securely hold the accelerometer in place while allowing for precise measurements. Like the Main Controller Unit, it consists of a base and a lid.

### 11.2.1 Accelerometer Base

- The base is designed to provide a stable platform for the accelerometer.
- It includes features for mounting the accelerometer securely and provisions for cable management.

### 11.2.2 Accelerometer Lid

- The lid is designed to protect the accelerometer while allowing it to perform measurements accurately.
- It includes features for securing the lid to the base, such as screw holes.

### 11.2.3 Assembly

- The assembly involves securing the accelerometer within the base and attaching the lid.
- The design ensures easy access to the accelerometer for maintenance while providing robust protection.

51

### 11.2.4 Figures

Design Tree

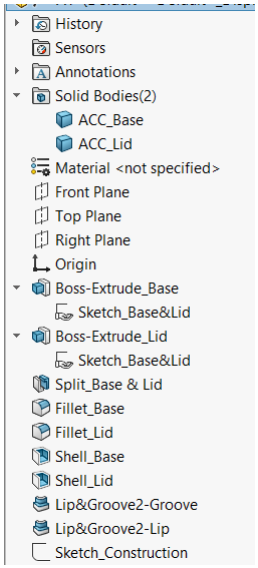
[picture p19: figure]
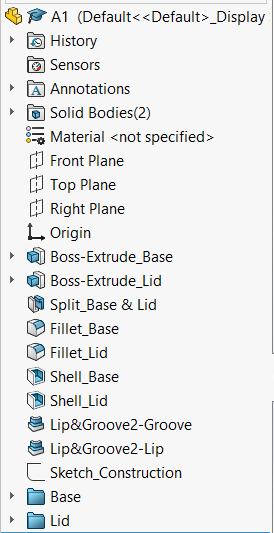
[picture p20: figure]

Figure 24: Design Tree of Accelerometer

52

Figure 25: Design Tree of Accelerometer Base

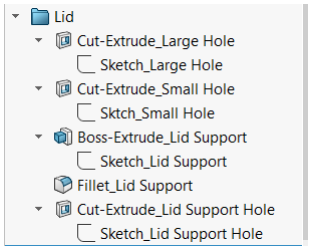
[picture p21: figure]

Figure 26: Design Tree of Accelerometer Lid

53

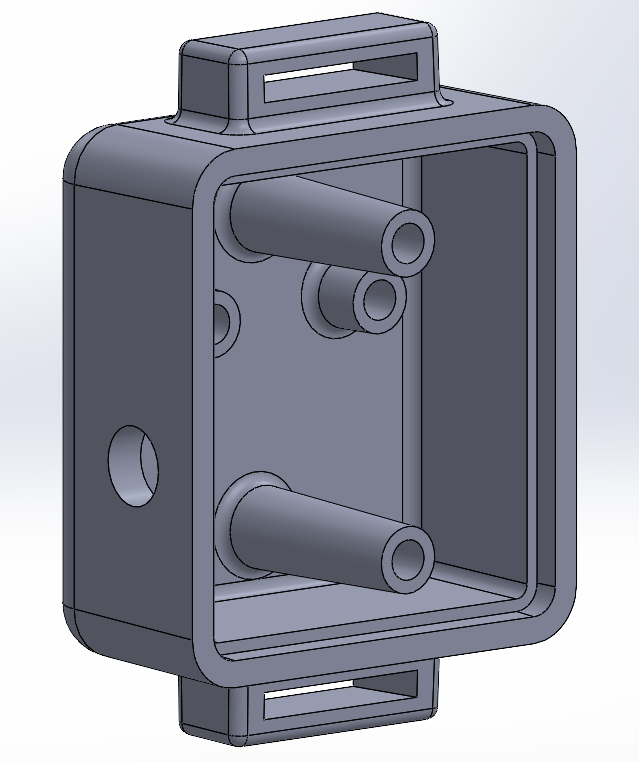
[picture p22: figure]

Figure 27: Accelerometer Holding Part Base

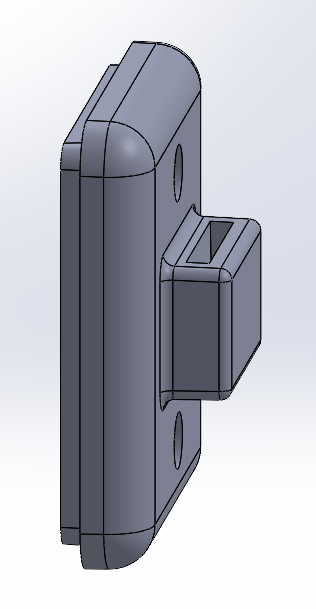
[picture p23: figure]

Figure 28: Accelerometer Holding Part Lid

54

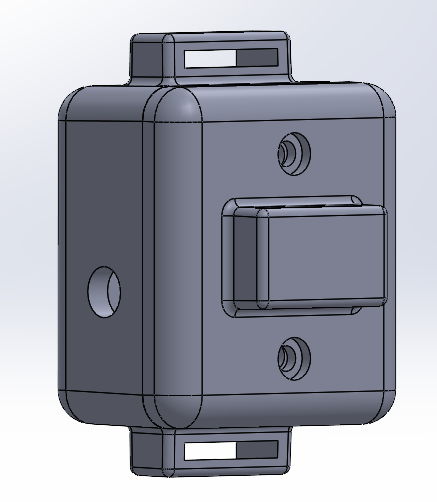
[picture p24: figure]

Figure 29: Accelerometer Holding Part Assembly

### 11.3 Conclusion

Both designs ensure that the components are securely housed and protected while allowing for efficient assembly and maintenance. The moldable design of these parts facilitates cost-effective manufacturing and ensures durability and reliability in their application.

55

## References

[1] icrochip | Technology, | 8-bit | AVR | Microcontroller | with | 32K | Bytes
In-System | Programmable | Flash. | Version | 7810D–AVR–01/15. | Avail-
able | at: | https://ww1.microchip.com/downloads/en/DeviceDoc/
Atmel-7810-Automotive-Microcontrollers-ATmega328P_Datasheet.pdf (https://ww1.microchip.com/downloads/en/DeviceDoc/Atmel-7810-Automotive-Microcontrollers-ATmega328P_Datasheet.pdf)
[2] anjing Qinheng Microelectronics, USB to Serial Port Chip. Sheet version 2C. Available at: https://www.mpja.com/download/35227cpdata.pdf
[3] DK InvenSense, MPU-6050 Six-Axis (Gyro + Accelerometer) MEMS Motion-Tracking™ Device. Available at: https://invensense.tdk.com/wp-content/uploads/2015/02/MPU-6000-Datasheet1.pdf (https://invensense.tdk.com/wp-content/uploads/2015/02/MPU-6000-Datasheet1.pdf)
[4] ianchi, G. et al., 2014. ”Analysis of Vibration Damping in Machine Tools,” Procedia CIRP. Available at: https://www.researchgate.net/publication/275230904_Analysis_of_Vibration_Damping_in_Machine_Tools (https://www.researchgate.net/publication/275230904_Analysis_of_Vibration_Damping_in_Machine_Tools)
[5] setserukou, D., Kawakami, N., & Tachi, S. (2008). ”Vibration Damping Control of Robot Arm Intended for Service Application in Human Environment,” 2008 8th IEEE-RAS International Conference on Humanoid Robots (Humanoids 2008). DOI: 10.1109/ICHR.2008.4756002. (https://doi.org/10.1109/ICHR.2008.4756002) Available at: https://www.researchgate.net/publication/224373517_Vibration_damping_control_of_robot_arm_intended_for_service_application_in_human_environment (https://www.researchgate.net/publication/224373517_Vibration_damping_control_of_robot_arm_intended_for_service_application_in_human_environment)
[6] ord, D.G., Myers, A., Haase, F., Lockwood, S., & Longstaff, A.P. (2013). ”Active Vibration Control for a CNC Milling Machine,” Proceedings of the Institution of Mechanical Engineers, Part C: Journal of Mechanical Engineering Science. DOI: 10.1177/0954406213484224. (https://doi.org/10.1177/0954406213484224) Available at: https://www.academia.edu/56290445/Active_vibration_control_for_a_CNC_milling_machine (https://www.academia.edu/56290445/Active_vibration_control_for_a_CNC_milling_machine)
[7] hen, | F., | Hanifzadegan, | M., | Altintas, | Y., | & Lu, | X. (2015). ”Ac-
tive Damping of Boring Bar Vibration With a Magnetic Actuator,”
IEEE/ASME Transactions on Mechatronics, | 20(6), | 1-12. DOI: Avail-
able at: | https://www.researchgate.net/publication/276383735_Active_
Damping_of_Boring_Bar_Vibration_With_a_Magnetic_Actuator (https://www.researchgate.net/publication/276383735_Active_Damping_of_Boring_Bar_Vibration_With_a_Magnetic_Actuator)
[8] kbar, M.A., Wong, W.-O., & Rustighi, E. (2023). ”A Hybrid Damper with Tunable Particle Impact Damping and Coulomb Friction,” Machines, 11(5), 545. DOI: 10.3390/machines11050545. (https://doi.org/10.3390/machines11050545) Available at: https://www.mdpi.com/2075-1702/11/5/545 (https://www.mdpi.com/2075-1702/11/5/545)
[9] andvik Coromant - Silent Tools™ Turning Adapters: https://www.sandvik.coromant.com/en-us/tools/turning-tools/internal-turning-tools/silent-tools-turning (https://www.sandvik.coromant.com/en-us/tools/turning-tools/internal-turning-tools/silent-tools-turning)
[10] ig Daishowa - Smart Damper: https://www.bigkaiser.eu/en/products/damping-tools.html (https://www.bigkaiser.eu/en/products/damping-tools.html)

56

[11] eco Tools - Steadyline® Vibration Damping System: https://www.secotools.com/article/20850 (https://www.secotools.com/article/20850)

57

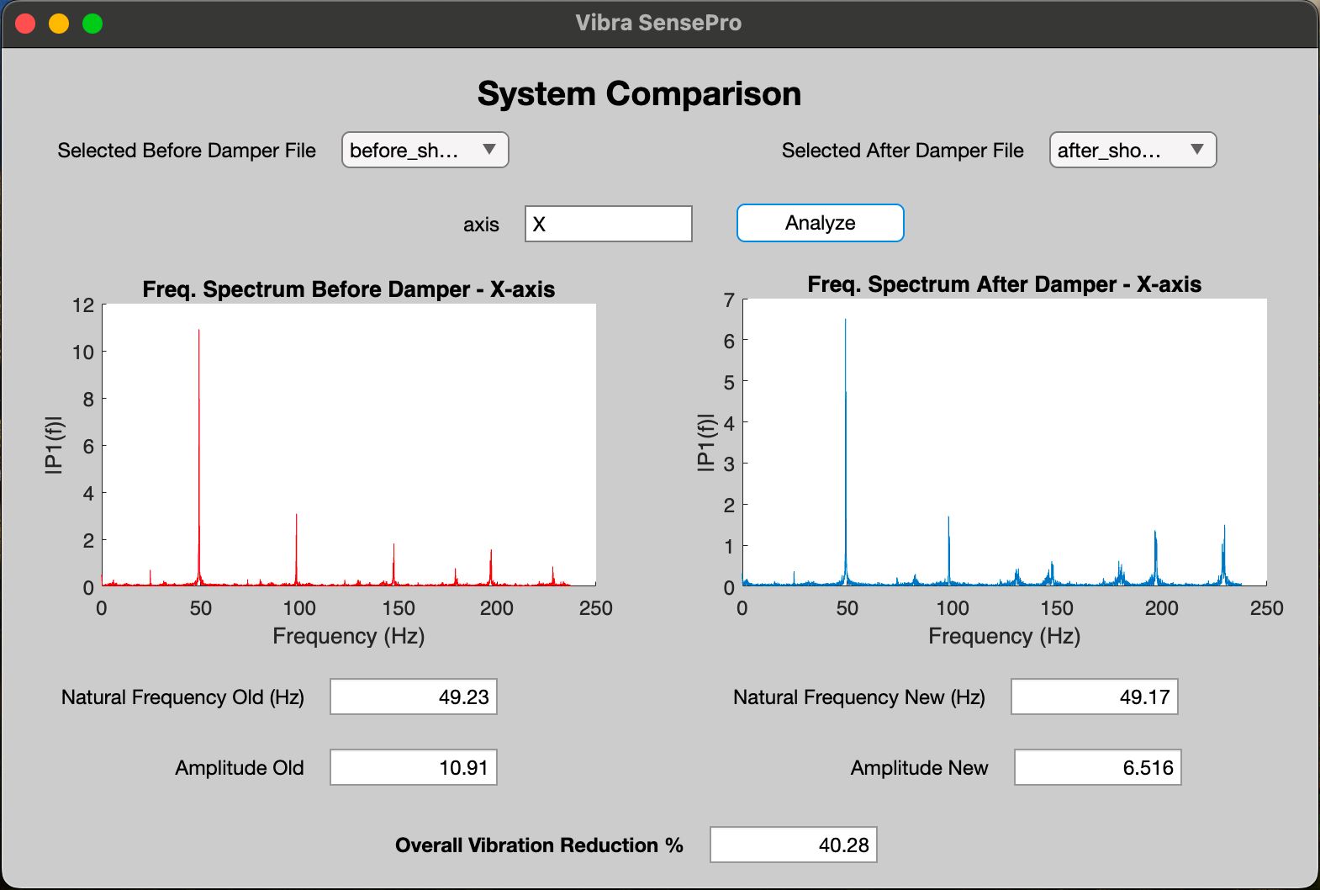
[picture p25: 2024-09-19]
MATLAB Application for Data Analysis/Images/Window4.jpeg

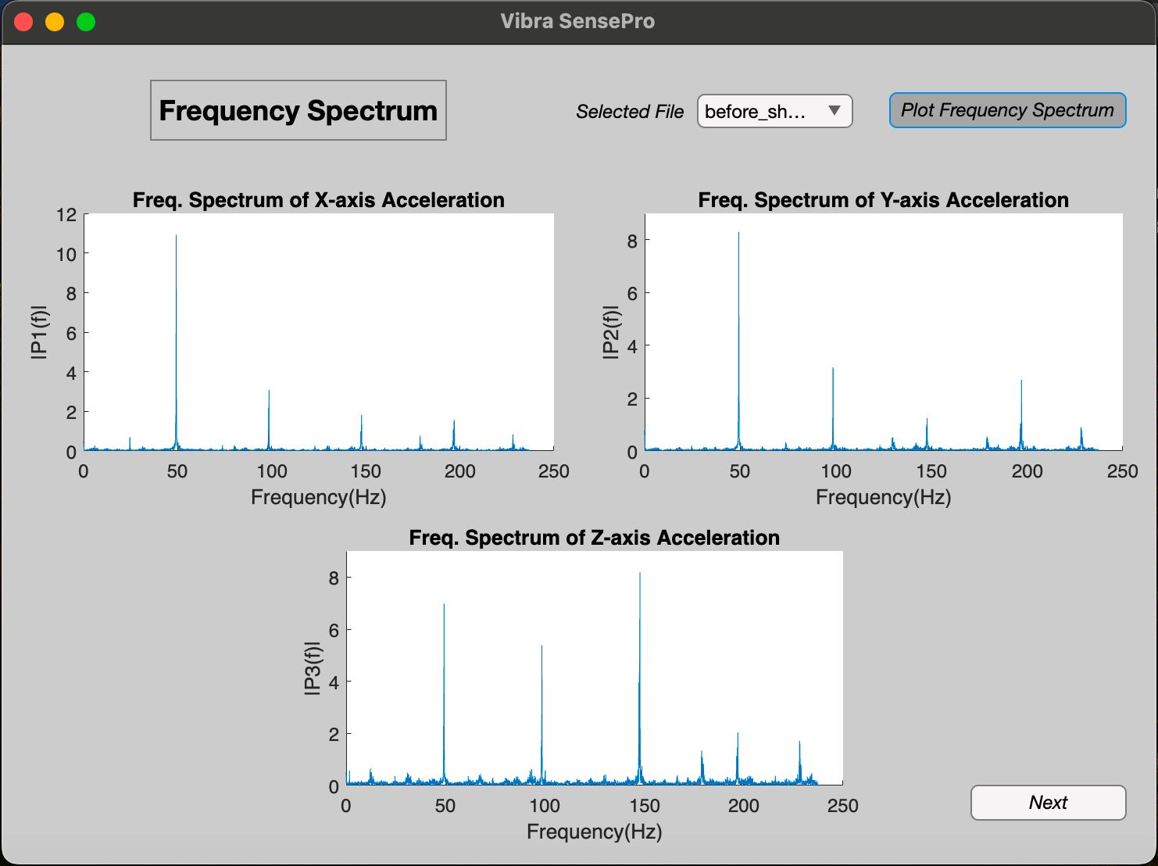
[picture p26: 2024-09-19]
MATLAB Application for Data Analysis/Images/Window2.jpeg

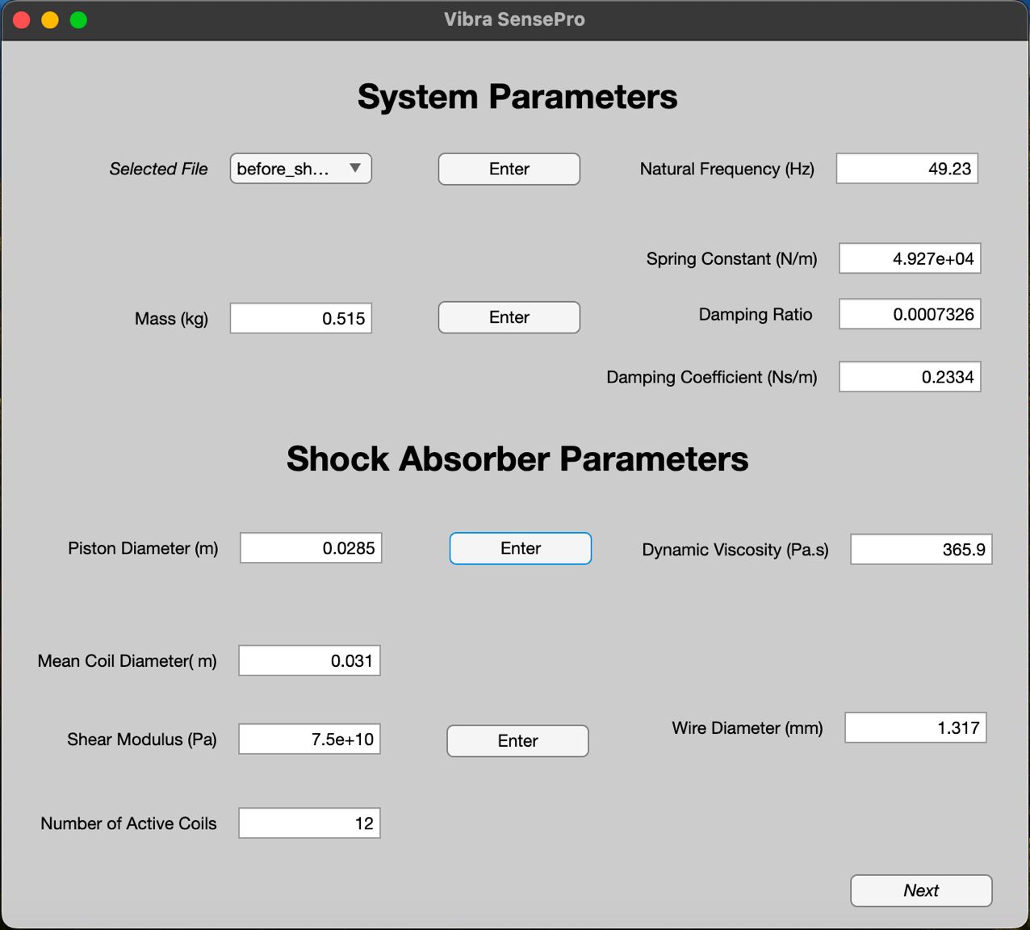
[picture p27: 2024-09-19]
MATLAB Application for Data Analysis/Images/Window3.jpeg

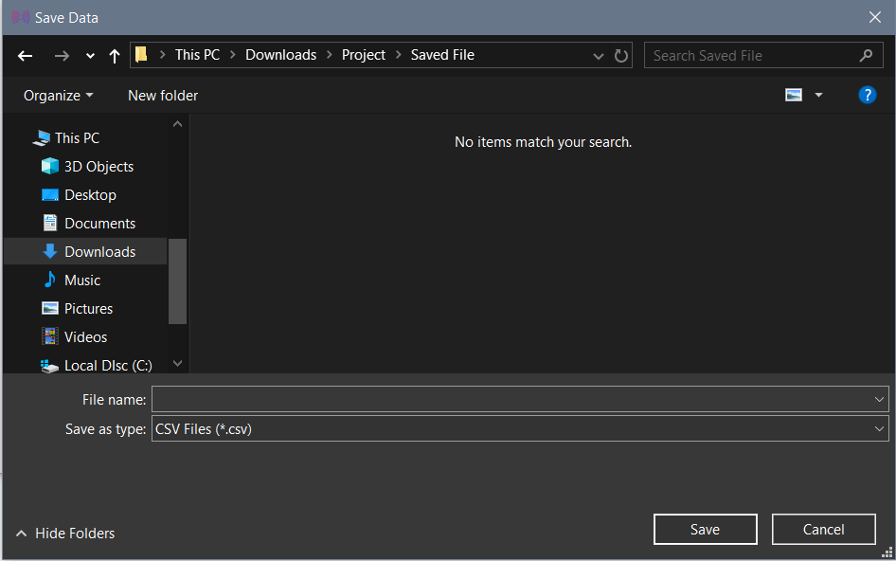
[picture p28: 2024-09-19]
UI for Data Acquisition System/Images/6.Save_Data.PNG

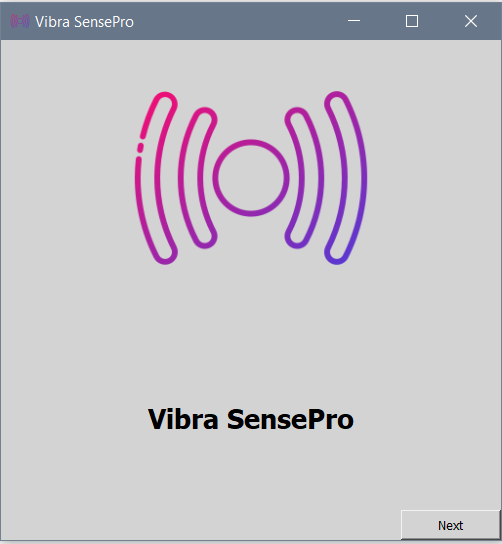
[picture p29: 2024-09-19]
UI for Data Acquisition System/Images/1.Start.PNG

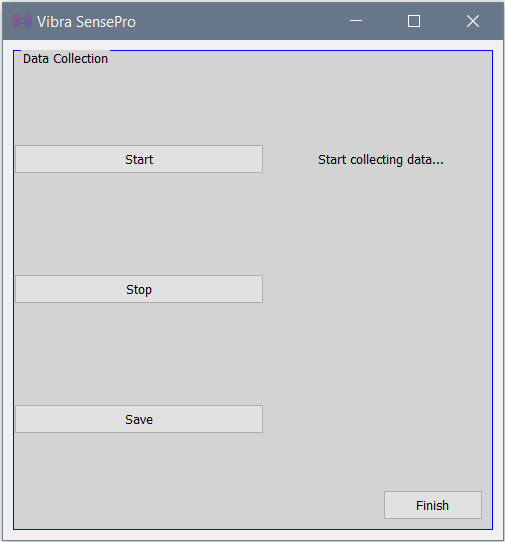
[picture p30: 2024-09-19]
UI for Data Acquisition System/Images/4.Start_Data Collection.PNG

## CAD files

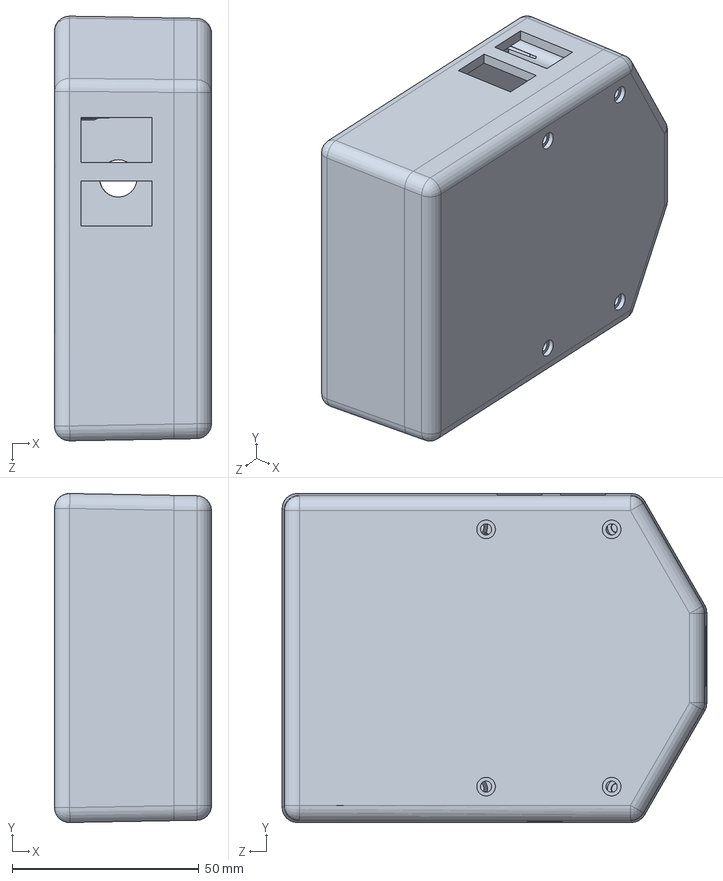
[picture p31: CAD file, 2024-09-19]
Enclosure Design-SolidWorks/Main_Controller_Unit/Main_Controller_Unit.SLDPRT
42.0 x 88.0 x 113.6 mm

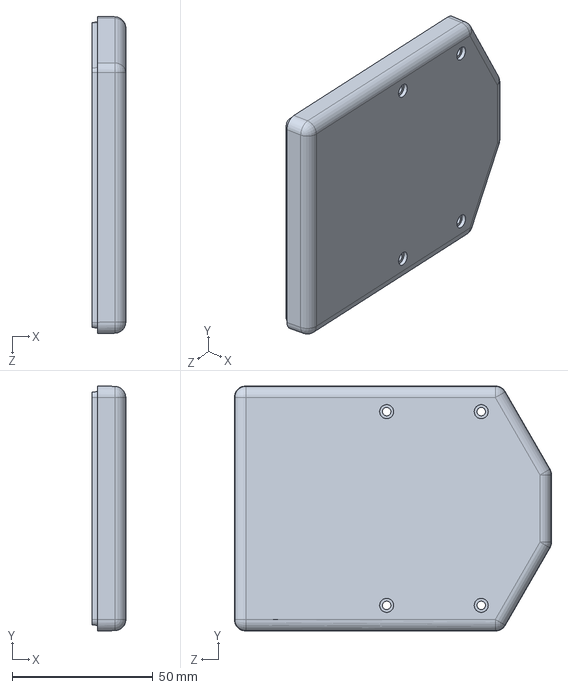
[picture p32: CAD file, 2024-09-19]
Enclosure Design-SolidWorks/Main_Controller_Unit/Main_Controller_Unit_Lid.SLDPRT
12.0 x 87.0 x 112.6 mm

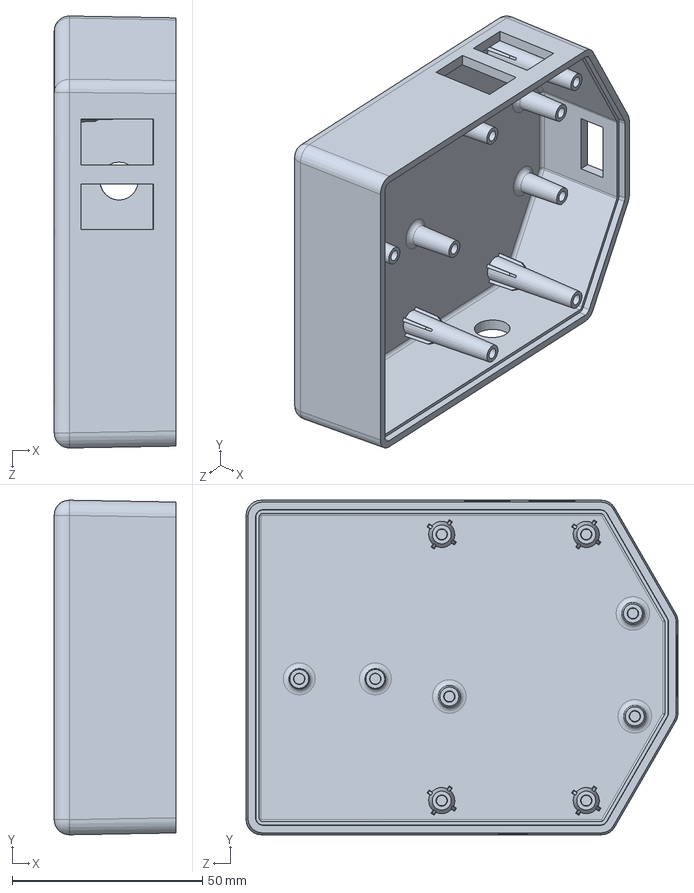
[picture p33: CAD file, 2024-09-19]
Enclosure Design-SolidWorks/Main_Controller_Unit/Main_Controller_Unit_Base.SLDPRT
32.0 x 88.0 x 113.6 mm

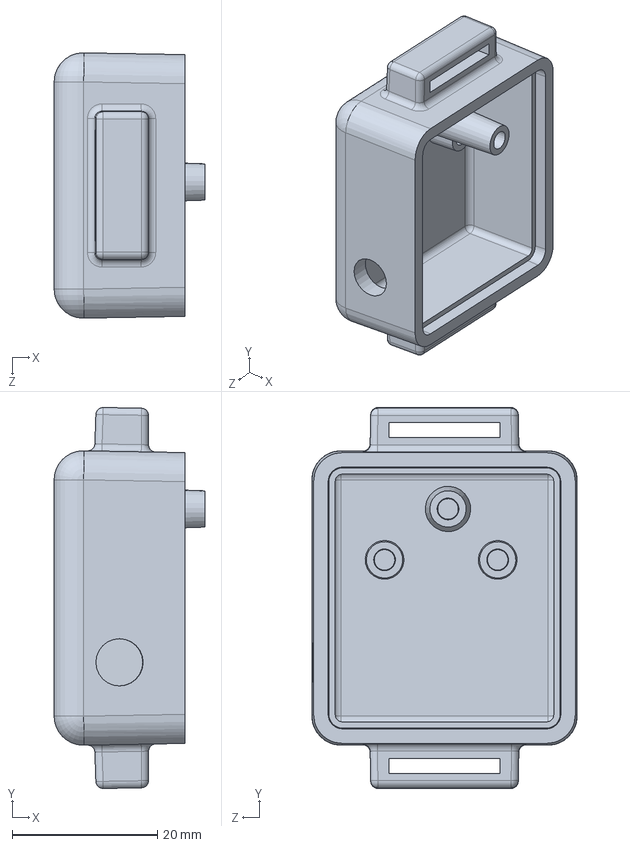
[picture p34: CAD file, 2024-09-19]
Enclosure Design-SolidWorks/Accelerometer/Accelerometer.SLDPRT
20.7 x 52.4 x 36.5 mm

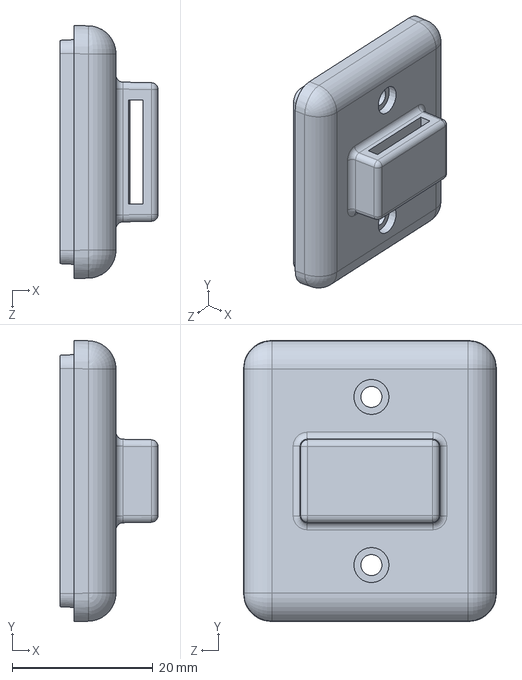
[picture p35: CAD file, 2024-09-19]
Enclosure Design-SolidWorks/Accelerometer/Accelerometer_Lid.SLDPRT
14.0 x 40.0 x 36.0 mm

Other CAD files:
Enclosure Design-SolidWorks/Accelerometer/Accelerometer_Base.SLDPRT

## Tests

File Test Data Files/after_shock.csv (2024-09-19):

AX | AY | AZ | Hours | Minutes | Seconds | Milliseconds
-16.50 | -10.58 | 19.62 | 00 | 00 | 17 | 684
-5.30 | -1.00 | -14.26 | 00 | 00 | 17 | 686
1.16 | 1.39 | 11.75 | 00 | 00 | 17 | 688
19.62 | 17.28 | 19.62 | 00 | 00 | 17 | 690
18.02 | 8.84 | -5.60 | 00 | 00 | 17 | 692
19.62 | -2.10 | -14.47 | 00 | 00 | 17 | 694
19.62 | 9.07 | 19.62 | 00 | 00 | 17 | 696
17.47 | -1.45 | -19.62 | 00 | 00 | 17 | 699
12.14 | -11.41 | 3.22 | 00 | 00 | 17 | 701
-18.88 | -11.57 | 2.53 | 00 | 00 | 17 | 703
-4.79 | -8.23 | 19.62 | 00 | 00 | 17 | 705
-14.96 | -2.74 | -19.62 | 00 | 00 | 17 | 707
6.50 | 10.20 | 19.62 | 00 | 00 | 17 | 709
19.62 | 19.62 | 19.62 | 00 | 00 | 17 | 711
9.76 | 1.16 | -19.62 | 00 | 00 | 17 | 713
19.62 | 1.48 | 6.52 | 00 | 00 | 17 | 715
19.62 | 6.14 | 5.72 | 00 | 00 | 17 | 717
4.20 | -7.87 | -19.62 | 00 | 00 | 17 | 720
3.41 | -14.47 | -14.55 | 00 | 00 | 17 | 722
-19.62 | -12.43 | 19.62 | 00 | 00 | 17 | 724
3.92 | -3.51 | -1.85 | 00 | 00 | 17 | 726
-9.67 | -2.76 | -15.19 | 00 | 00 | 17 | 728
19.62 | 17.17 | 19.62 | 00 | 00 | 17 | 730
19.62 | 17.15 | 19.62 | 00 | 00 | 17 | 732
14.83 | -4.08 | -19.62 | 00 | 00 | 17 | 734
19.62 | 5.92 | 19.62 | 00 | 00 | 17 | 736
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

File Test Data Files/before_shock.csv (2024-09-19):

AX | AY | AZ | Hours | Minutes | Seconds | Milliseconds
12.36 | 1.14 | -18.40 | 00 | 00 | 13 | 431
19.62 | 7.33 | -14.60 | 00 | 00 | 13 | 433
19.62 | 19.62 | 4.67 | 00 | 00 | 13 | 436
12.73 | 2.89 | -19.62 | 00 | 00 | 13 | 438
18.94 | -0.74 | -19.62 | 00 | 00 | 13 | 440
15.69 | -4.74 | 2.55 | 00 | 00 | 13 | 442
-19.62 | -11.43 | 5.83 | 00 | 00 | 13 | 444
-8.39 | -19.29 | -12.30 | 00 | 00 | 13 | 446
-6.80 | 5.60 | 19.62 | 00 | 00 | 13 | 448
2.06 | 5.52 | 19.62 | 00 | 00 | 13 | 450
14.61 | -1.65 | -19.62 | 00 | 00 | 13 | 452
19.62 | 11.18 | 3.61 | 00 | 00 | 13 | 454
19.62 | 19.62 | -14.64 | 00 | 00 | 13 | 457
5.79 | -4.23 | -19.62 | 00 | 00 | 13 | 459
19.62 | 4.70 | -19.62 | 00 | 00 | 13 | 461
-17.58 | -14.41 | 19.62 | 00 | 00 | 13 | 463
-19.62 | -12.90 | -9.00 | 00 | 00 | 13 | 465
-5.55 | -19.62 | -19.62 | 00 | 00 | 13 | 467
-2.16 | 7.95 | 19.62 | 00 | 00 | 13 | 469
17.54 | 3.76 | 19.62 | 00 | 00 | 13 | 471
19.62 | 2.21 | -19.62 | 00 | 00 | 13 | 474
19.62 | 19.62 | 14.44 | 00 | 00 | 13 | 476
19.62 | 19.62 | -19.62 | 00 | 00 | 13 | 478
19.62 | 1.32 | -19.62 | 00 | 00 | 13 | 480
9.92 | -7.18 | 17.01 | 00 | 00 | 13 | 482
-19.62 | -12.06 | 19.62 | 00 | 00 | 13 | 484
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

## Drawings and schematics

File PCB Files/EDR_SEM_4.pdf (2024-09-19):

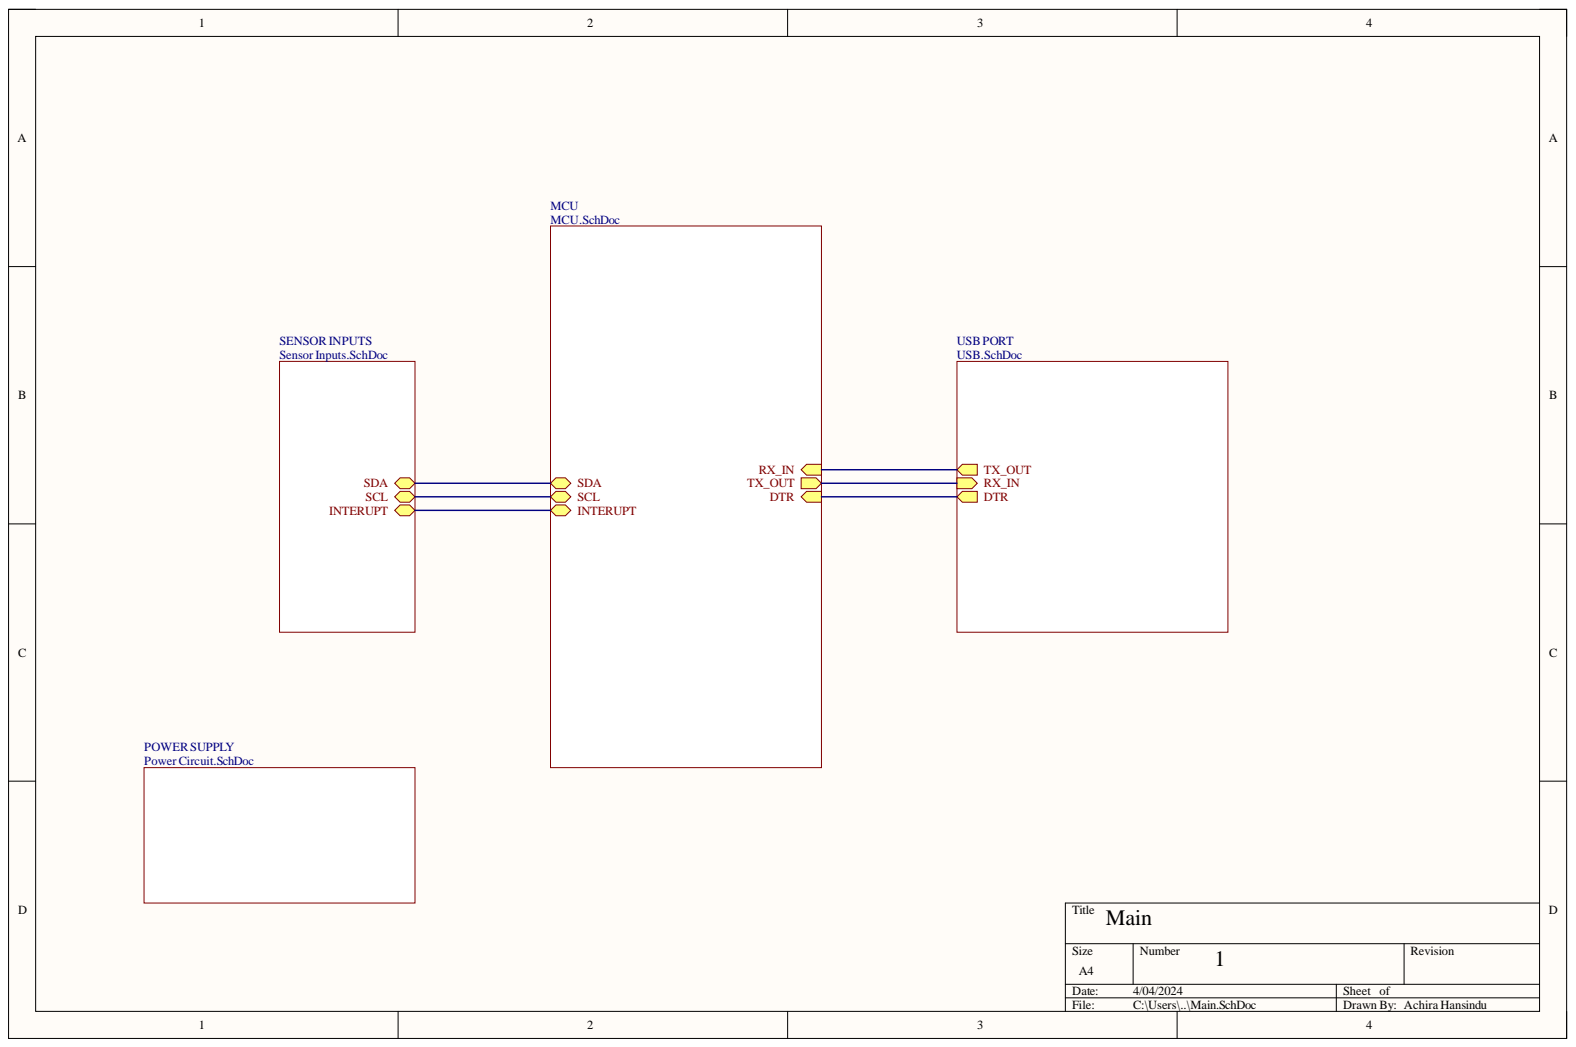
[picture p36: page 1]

Size A4 | Number 1 | Revision

Date: 4/04/2024 | Sheet of
File: C:\Users\..\Main.SchDoc | Drawn By: Achira Hansindu

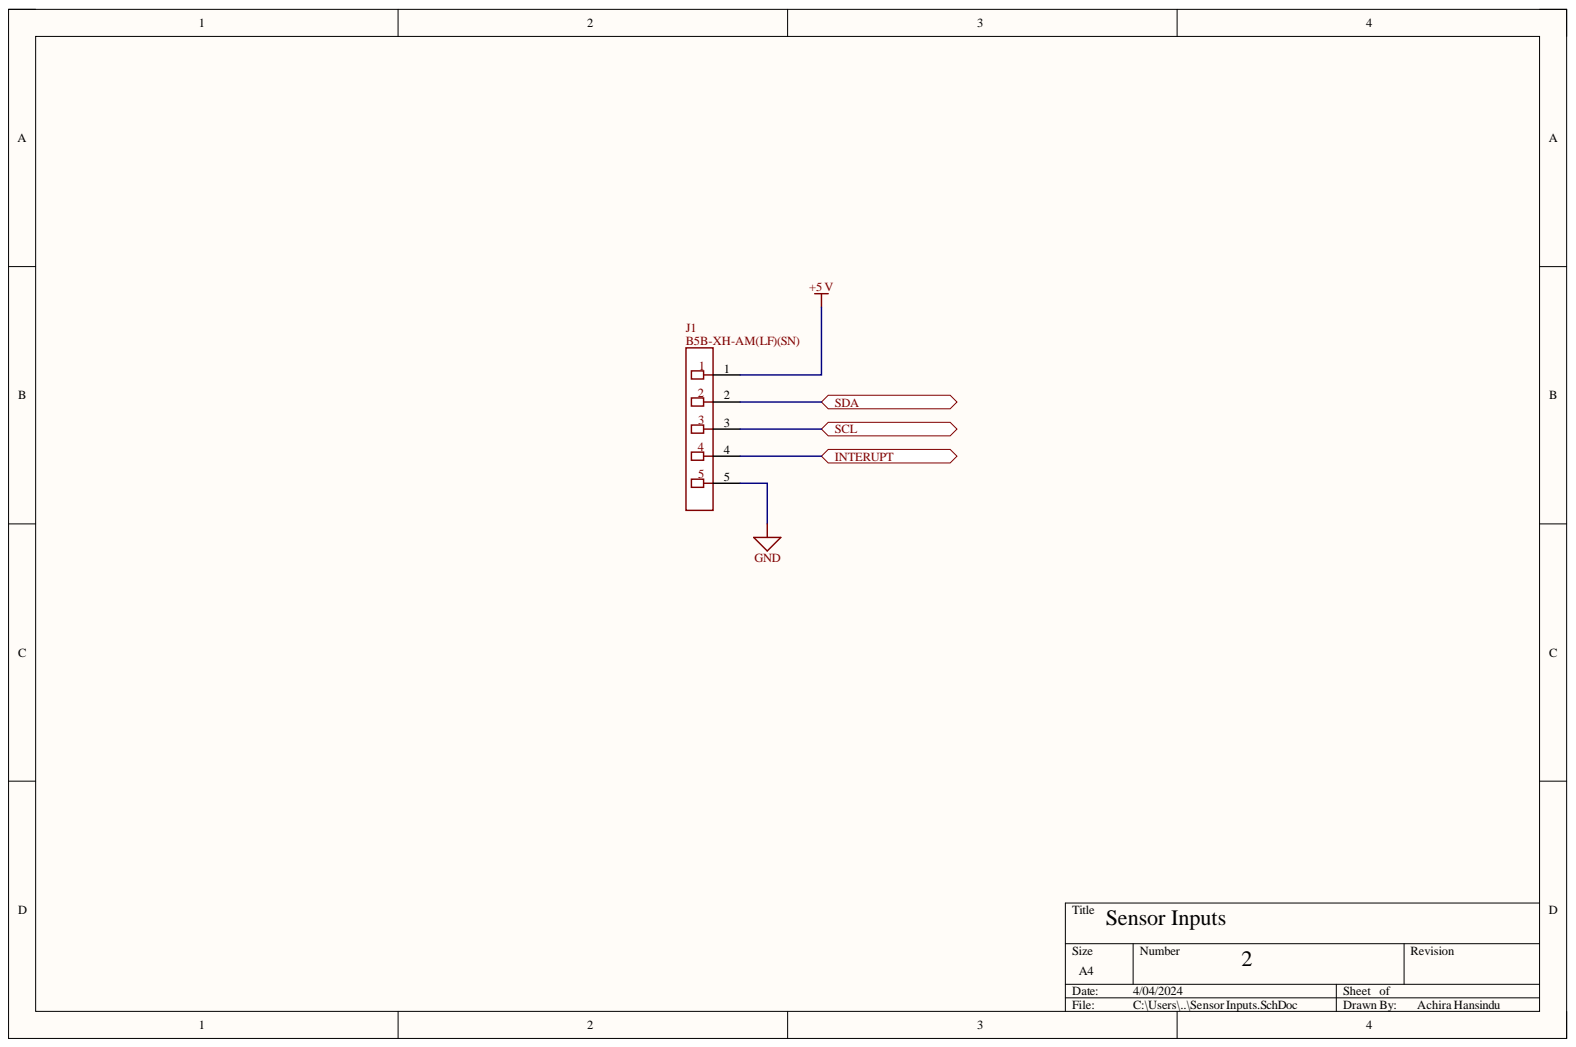
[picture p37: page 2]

Size A4 | Number 2 | Revision

Date: 4/04/2024 | Sheet of
File: C:\Users\..\SensorInputs.SchDoc | Drawn By: Achira Hansindu

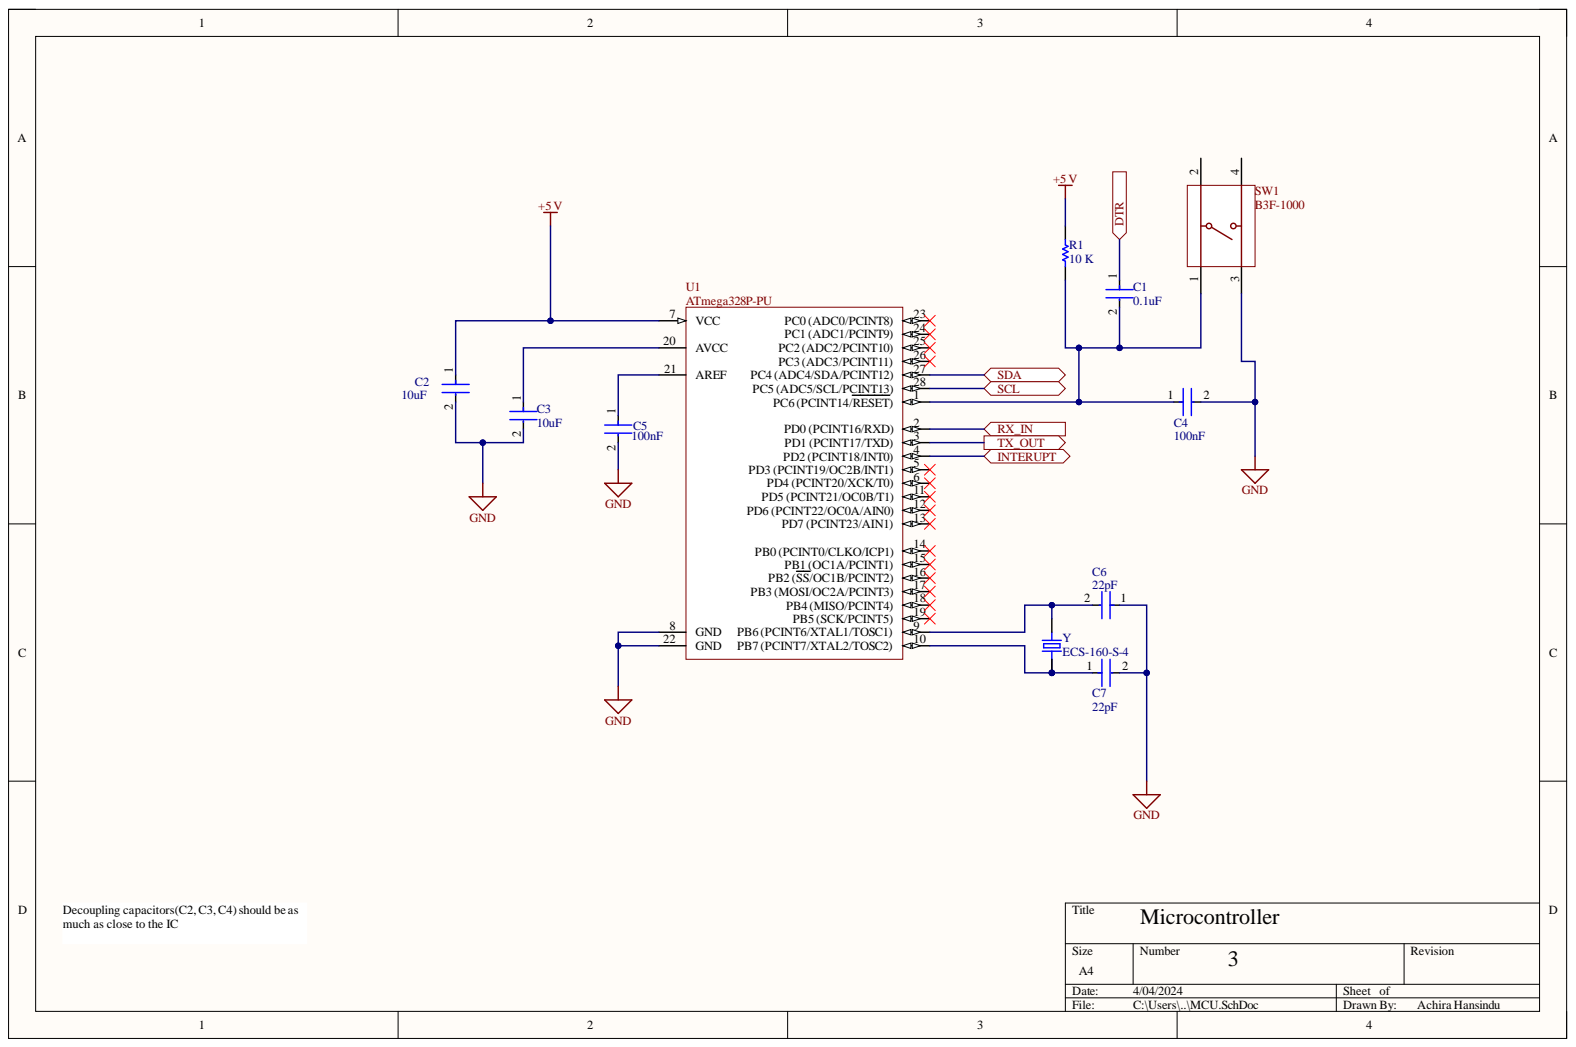
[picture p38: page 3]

Microcontroller Decoupling capacitors(C2,C3,C4)should be as
much

Siz e A4 | Numb e r 3 | R evisio n

Da te : 4/04/202 4 | She et of
File : C:\Use rs\. .\MCU. S c hD o c | Dr awn B y : Achir a Hansi n du

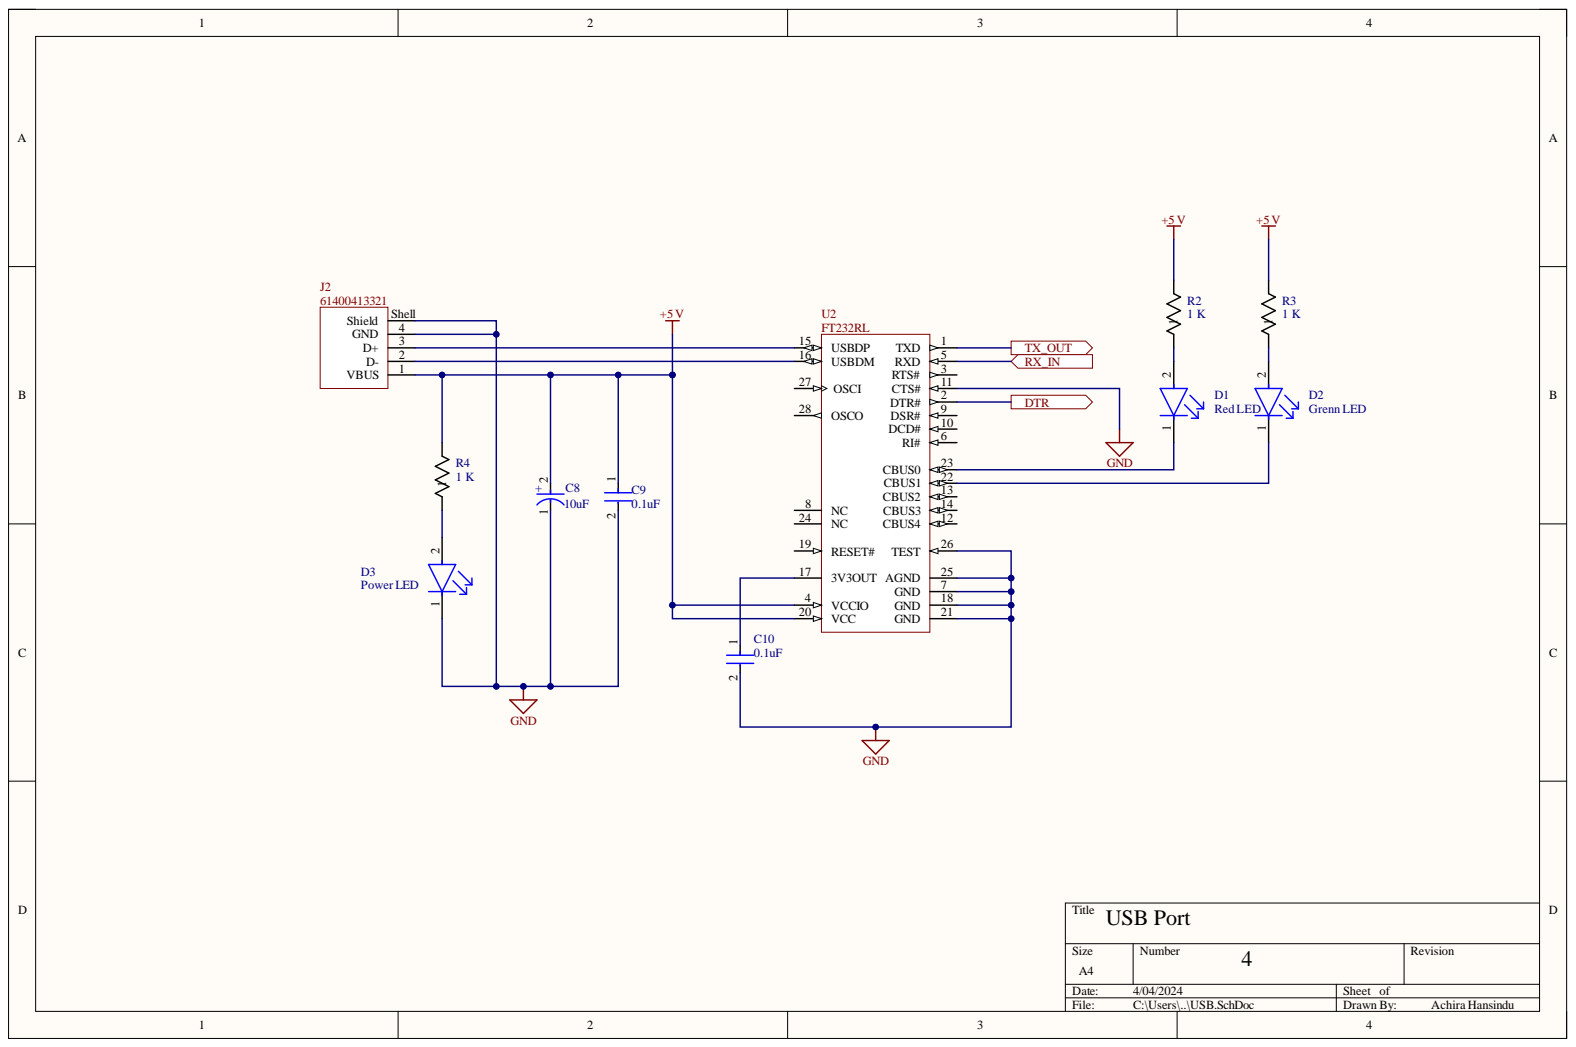
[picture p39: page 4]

Siz e A4 | Numb e r 4 | R evisio n

Da te : 4/04/202 4 | She et of
File : C:\Use rs\. .\US B . S c hD o c | Dr awn B y : Achir a Hansi n du

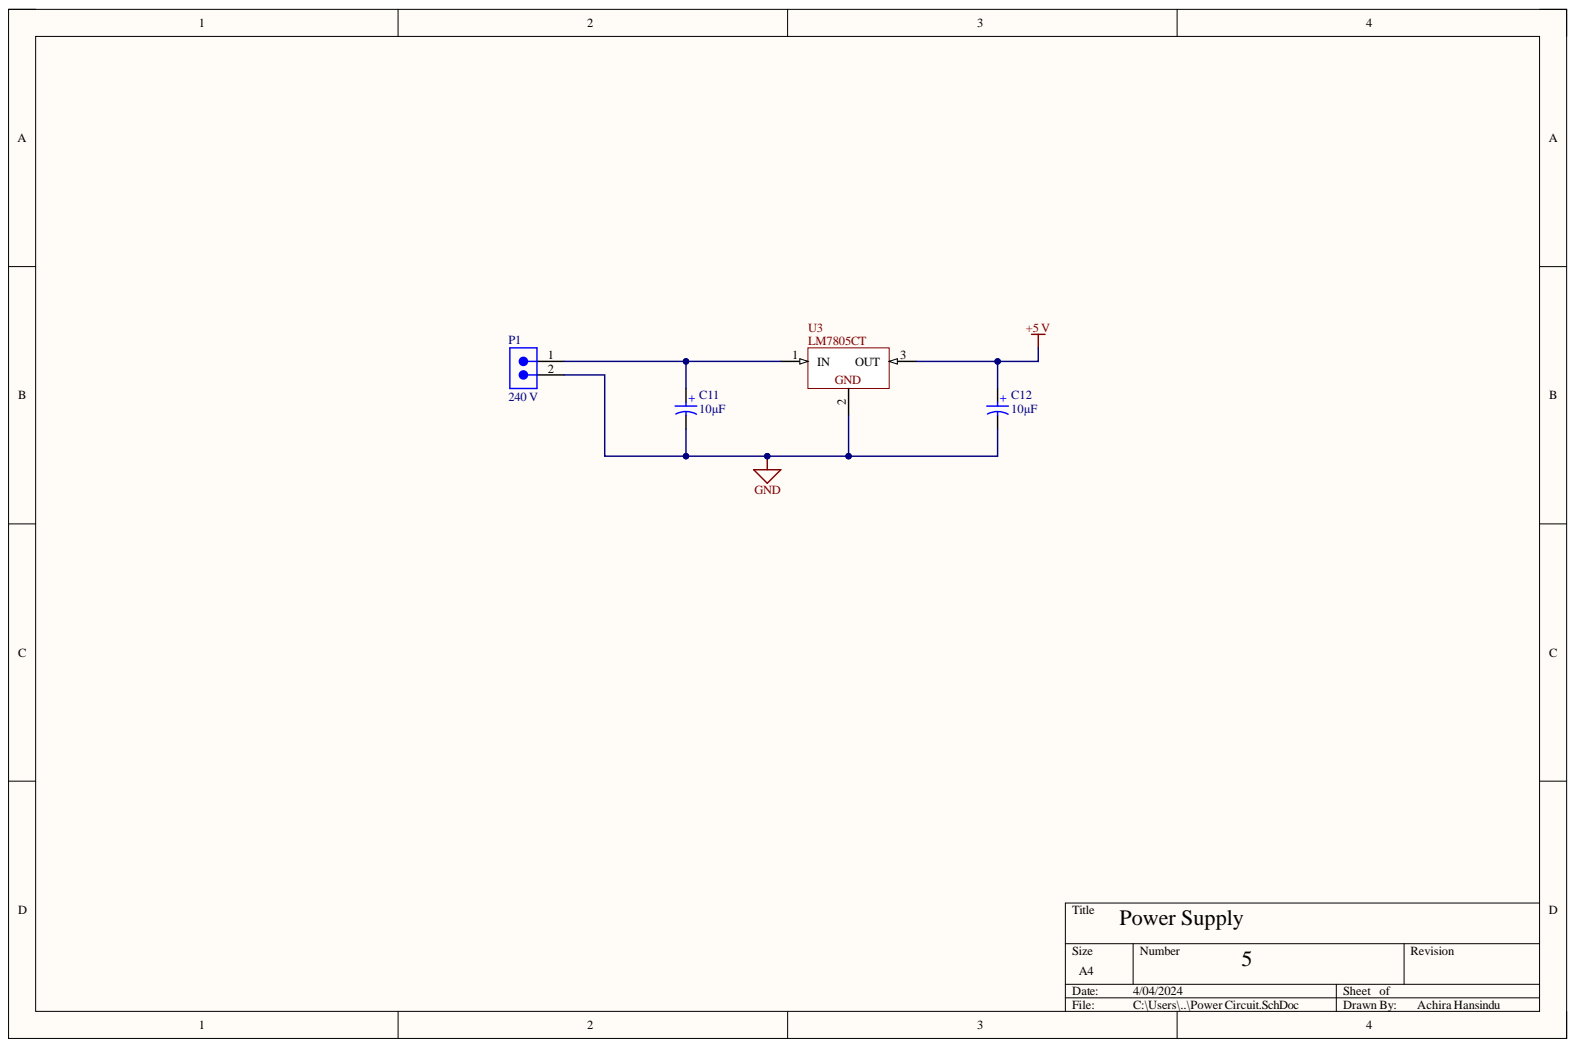
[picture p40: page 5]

Siz e A4 | Numb e r 5 | R evisio n

Da te : 4/04/202 4 | She et of
File : C:\Use rs\. .\Powe r Cir cuit . S c hD o c | Dr awn B y : Achir a Hansi n du

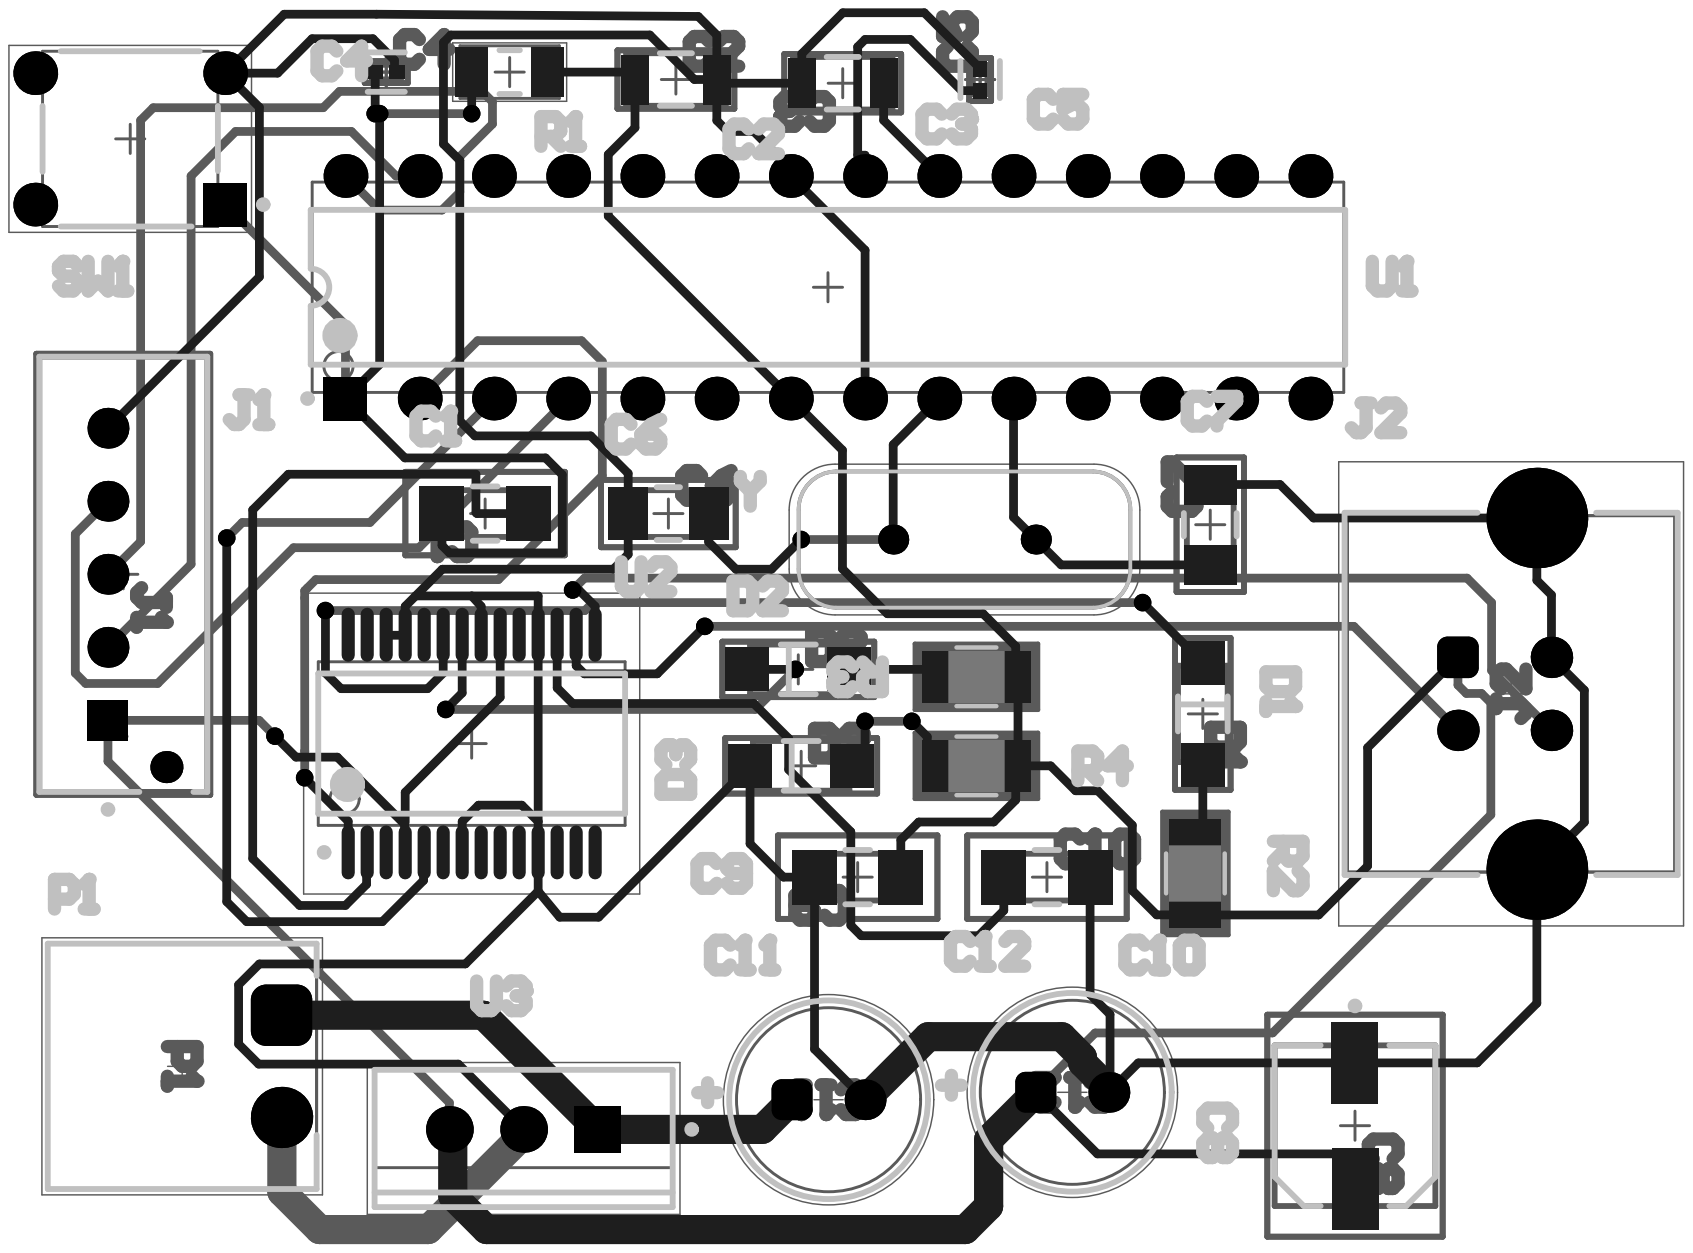
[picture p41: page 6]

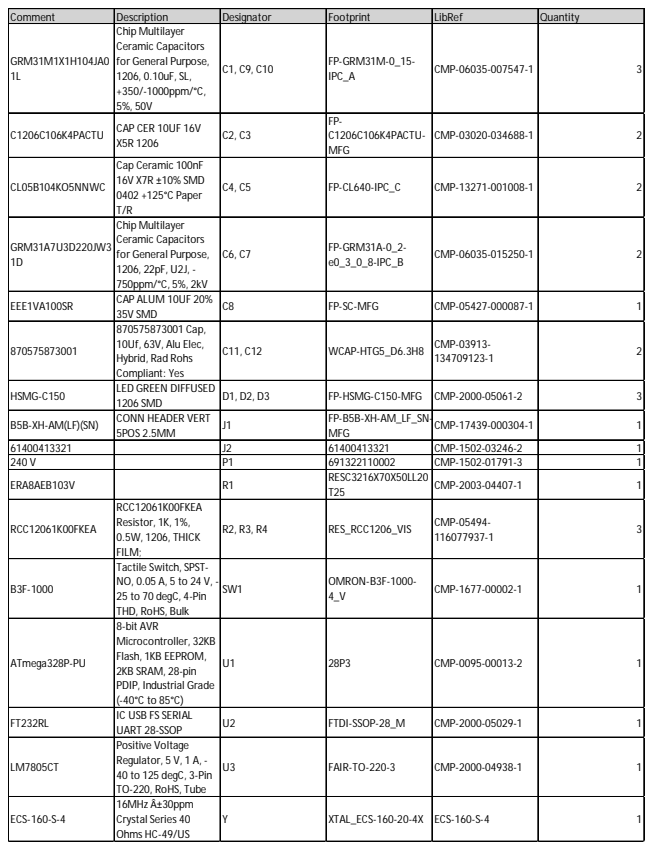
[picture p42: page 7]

Comment | Description | Designator | Footprint | LibRef | Quantity
GRM31M1X1H104JA0 1L | Chip Multilayer Ceramic Capacitors for General Purpose, 1206, 0.10uF, SL, +350/-1000ppm/°C, 5%, 50V | C1, C9, C10 | FP-GRM31M-0_15-IPC_A | CMP-06035-007547-1 | 3

C1206C106K4PACTU | CAP CER 10UF 16V X5R 1206 | C2, C3 | FP-C1206C106K4PACTU-MFG | CMP-03020-034688-1 | 2

CL05B104KO5NNWC | Cap Ceramic 100nF 16V X7R ±10% SMD 0402 +125°C Paper T/R | C4, C5 | FP-CL640-IPC_C | CMP-13271-001008-1 | 2

GRM31A7U3D220JW3 1D | Chip Multilayer Ceramic Capacitors for General Purpose, 1206, 22pF, U2J, -750ppm/°C, 5%, 2kV | C6, C7 | FP-GRM31A-0_2-e0_3_0_8-IPC_B | CMP-06035-015250-1 | 2

EEE1VA100SR | CAP ALUM 10UF 20% 35V SMD | C8 | FP-SC-MFG | CMP-05427-000087-1 | 1

870575873001 | 870575873001 Cap, 10Uf, 63V, Alu Elec, Hybrid, Rad Rohs Compliant: Yes | C11, C12 | WCAP-HTG5_D6.3H8 | CMP-03913-134709123-1 | 2

HSMG-C150 | LED GREEN DIFFUSED 1206 SMD | D1, D2, D3 | FP-HSMG-C150-MFG | CMP-2000-05061-2 | 3

B5B-XH-AM(LF)(SN) | CONN HEADER VERT 5POS 2.5MM | J1 | FP-B5B-XH-AM_LF_SN-MFG | CMP-17439-000304-1 | 1

61400413321 | | J2 | 61400413321 | CMP-1502-03246-2 | 1
240 V | | P1 | 691322110002 | CMP-1502-01791-3 | 1
ERA8AEB103V | | R1 | RESC3216X70X50LL20 T25 | CMP-2003-04407-1 | 1

RCC12061K00FKEA | RCC12061K00FKEA Resistor, 1K, 1%, 0.5W, 1206, THICK FILM; | R2, R3, R4 | RES_RCC1206_VIS | CMP-05494-116077937-1 | 3

B3F-1000 | Tactile Switch, SPST-NO, 0.05 A, 5 to 24 V, -25 to 70 degC, 4-Pin THD, RoHS, Bulk | SW1 | OMRON-B3F-1000-4_V | CMP-1677-00002-1 | 1

ATmega328P-PU | 8-bit AVR Microcontroller, 32KB Flash, 1KB EEPROM, 2KB SRAM, 28-pin PDIP, Industrial Grade (-40°C to 85°C) | U1 | 28P3 | CMP-0095-00013-2 | 1

FT232RL | IC USB FS SERIAL UART 28-SSOP | U2 | FTDI-SSOP-28_M | CMP-2000-05029-1 | 1

LM7805CT | Positive Voltage Regulator, 5 V, 1 A, -40 to 125 degC, 3-Pin TO-220, RoHS, Tube | U3 | FAIR-TO-220-3 | CMP-2000-04938-1 | 1

ECS-160-S-4 | 16MHz Â±30ppm Crystal Series 40 Ohms HC-49/US | Y | XTAL_ECS-160-20-4X | ECS-160-S-4 | 1

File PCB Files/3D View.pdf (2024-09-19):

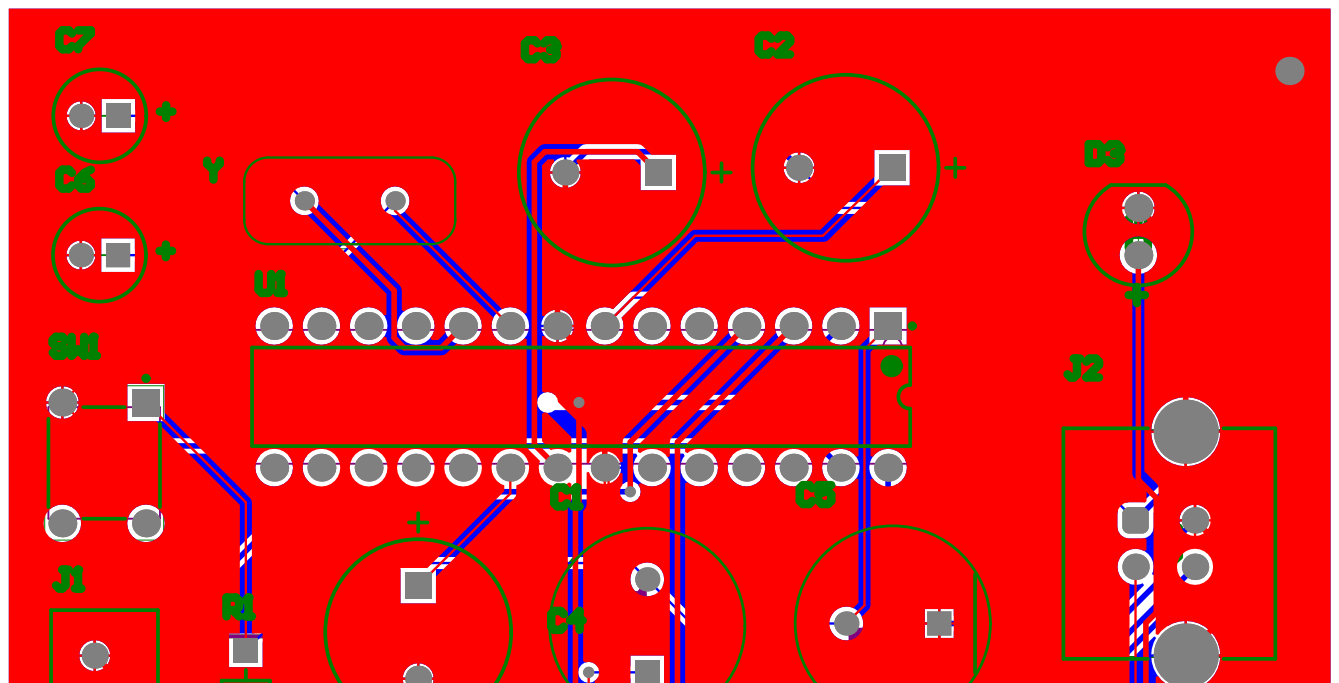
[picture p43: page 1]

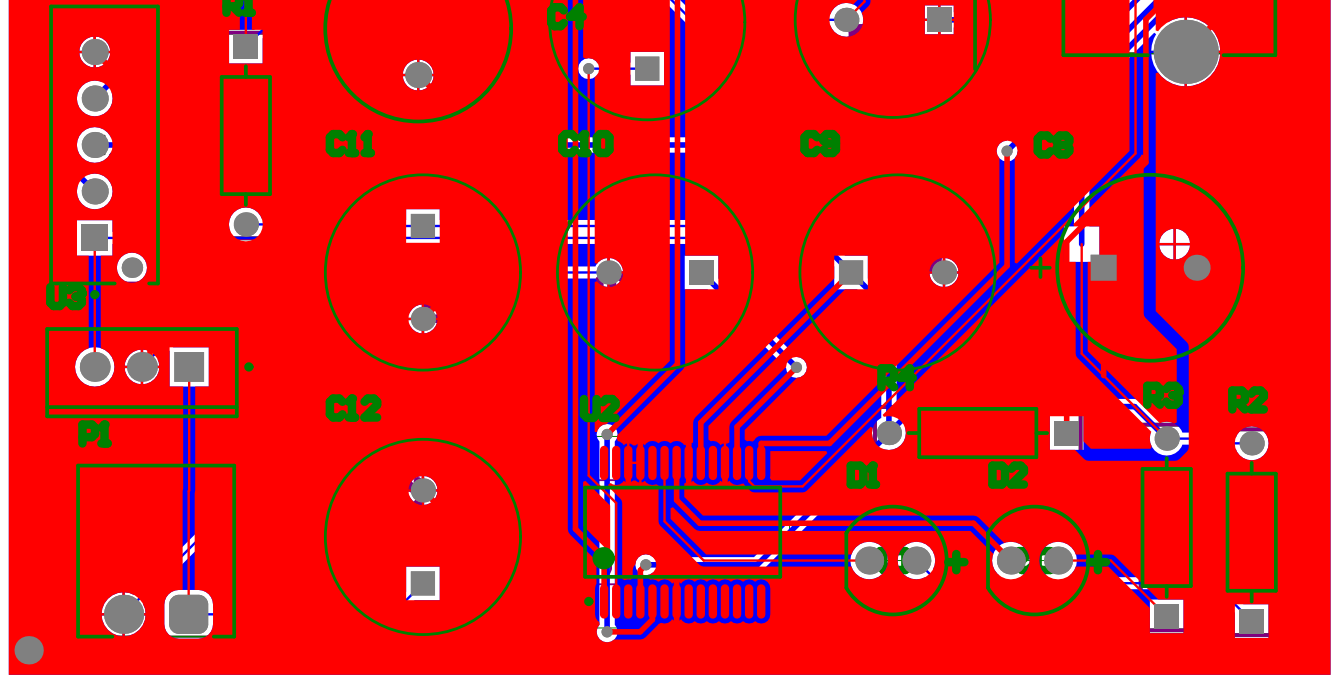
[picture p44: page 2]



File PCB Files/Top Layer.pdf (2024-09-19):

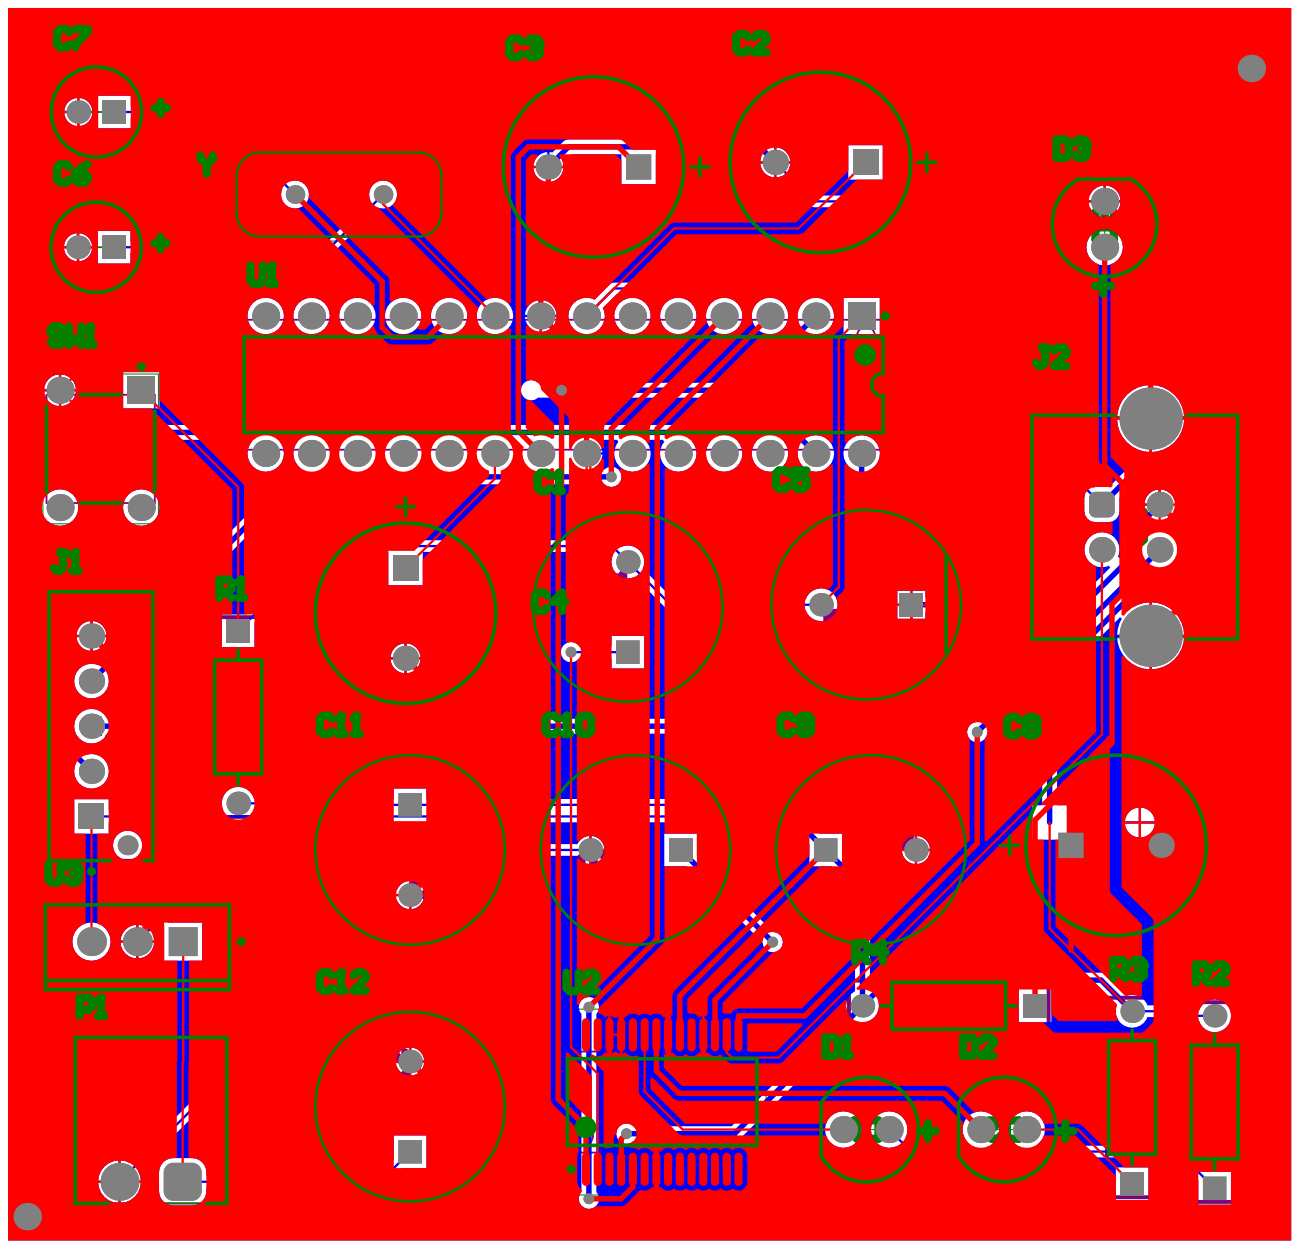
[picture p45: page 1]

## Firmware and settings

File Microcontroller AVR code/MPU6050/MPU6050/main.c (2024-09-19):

/**
 * @file MPU_Accel_Measurement.c
 * @brief Implements accelerometer data reading using MPU6050 and TWI.
 * 
 * This file contains the main logic to initialize the MPU6050 sensor, configure 
 * Timer1 for periodic interrupts, and read and process accelerometer data.
 * 
 * @Achira Hansindu
 * @date 14-Aug-24
 * @version 1.0
 */


#include "uart.h"                 // Include UART library for serial communication
#include "twi_master.h"           // Include TWI (I2C) library for communication with MPU6050
#include <avr/io.h>               // Include AVR I/O library for accessing registers
#include <avr/interrupt.h>        // Include AVR interrupt library for handling interrupts
#include <stdio.h>                // Include standard I/O library for printf function

#define MPU_ADDRESS       0x68    // I2C address of the MPU6050 sensor
#define ACCEL_X_H         0x3B    // Register address for high byte of X-axis accelerometer data
#define ACCEL_X_L         0x3C    // Register address for low byte of X-axis accelerometer data
#define ACCEL_Y_H         0x3D    // Register address for high byte of Y-axis accelerometer data
#define ACCEL_Y_L         0x3E    // Register address for low byte of Y-axis accelerometer data
#define ACCEL_Z_H         0x3F    // Register address for high byte of Z-axis accelerometer data
#define ACCEL_Z_L         0x40    // Register address for low byte of Z-axis accelerometer data
#define PWR_MGMT          0x6B    // Register address for power management

typedef struct
{
	float x_axis;                 // Floating point variable to store X-axis acceleration
	float y_axis;                 // Floating point variable to store Y-axis acceleration
	float z_axis;                 // Floating point variable to store Z-axis acceleration
} accel_t;

volatile uint32_t millis_count = 0;   // Counter for milliseconds
volatile uint8_t sec_count = 0;       // Counter for seconds
volatile uint8_t min_count = 0;       // Counter for minutes
volatile uint8_t read_flag = 0;       // Flag to indicate that it's time to read data

// Function to configure Timer1 for 1ms intervals
void timer1_config(void)
{
	TCCR1B |= (1 << WGM12);          // Set Timer1 to CTC mode
	TIMSK1 |= (1 << OCIE1A);         // Enable interrupt on compare match
	OCR1A = 249;                     // Set compare value for 1ms interval
	TCCR1B |= (1 << CS11) | (1 << CS10); // Start Timer1 with prescaler 64
}

// Function to handle errors by checking return codes
void handle_error(ret_code_t code)
{
	if (code != SUCCESS)             // If the code is not SUCCESS, there is an error
	{
		printf(BR "Error! Code = 0x%02X\n" RESET, code); // Print the error code
		while (1);                // Infinite loop to halt execution on error
	}
}

// Function to initialize the MPU6050 sensor
void mpu_initialize(void)
{
	ret_code_t code;
	uint8_t config_data[2] = {PWR_MGMT, 0}; // Data to wake up the MPU6050 (write 0 to PWR_MGMT register)
	code = tw_master_transmit(MPU_ADDRESS, config_data, sizeof(config_data), false); // Send data over I2C
	handle_error(code);              // Check if the transmission was successful
}

// Function to read raw accelerometer data from the MPU6050
void get_accel_raw(accel_t* accel_data)
{
	ret_code_t code;
	uint8_t data_buffer[6];          // Buffer to store the raw data from the sensor

	data_buffer[0] = ACCEL_X_H;      // Start reading from the X-axis high byte register
	code = tw_master_transmit(MPU_ADDRESS, data_buffer, 1, true); // Send register address
	handle_error(code);              // Check if the transmission was successful

	code = tw_master_receive(MPU_ADDRESS, data_buffer, sizeof(data_buffer)); // Read data from MPU6050
	handle_error(code);              // Check if the reception was successful

	// Combine high and low bytes and convert to floating-point values
	accel_data->x_axis = (int16_t)(data_buffer[0] << 8 | data_buffer[1]) / 16384.0;
	accel_data->y_axis = (int16_t)(data_buffer[2] << 8 | data_buffer[3]) / 16384.0;
	accel_data->z_axis = (int16_t)(data_buffer[4] << 8 | data_buffer[5]) / 16384.0;
}

// Function to convert raw accelerometer data to physical units (m/s^2)
void convert_accel_data(accel_t* accel_data)
{
	get_accel_raw(accel_data);       // Call function to get raw data
	accel_data->x_axis *= 9.81;      // Convert X-axis data to m/s^2
	accel_data->y_axis *= 9.81;      // Convert Y-axis data to m/s^2
	accel_data->z_axis *= 9.81;      // Convert Z-axis data to m/s^2
}

// Function to format a timestamp as a string
void format_timestamp(char *buffer)
{
	uint32_t milliseconds;
	uint8_t seconds, minutes, hours;

	cli();                           // Disable interrupts to prevent data inconsistency
	milliseconds = millis_count;     // Get current milliseconds count
	seconds = sec_count;             // Get current seconds count
	minutes = min_count;             // Get current minutes count
	sei();                           // Re-enable interrupts

	hours = minutes / 60;            // Calculate hours from minutes
	minutes = minutes % 60;          // Calculate remaining minutes

	// Format the timestamp as "HH.MM.SS.mmm"
	sprintf(buffer, "%02u.%02u.%02u.%03lu", hours, minutes, seconds, milliseconds % 1000);
}

// Interrupt Service Routine (ISR) for Timer1 Compare Match A
ISR(TIMER1_COMPA_vect)
{
	millis_count++;                  // Increment milliseconds counter

	if (millis_count >= 1000) {      // If 1000 milliseconds have passed
		millis_count = 0;           // Reset milliseconds counter
		sec_count++;                // Increment seconds counter
		
		if (sec_count >= 60) {      // If 60 seconds have passed
			sec_count = 0;         // Reset seconds counter
			min_count++;           // Increment minutes counter
			
			if (min_count >= 60) {  // If 60 minutes have passed
				min_count = 0;     // Reset minutes counter (one hour passed)
			}
		}
	}
	
	read_flag = 1;                   // Set flag to indicate it's time to read data
}

int main(void)
{
	uart_init(250000);               // Initialize UART with a baud rate of 250000
	cli_reset();                     // Clear interrupt flag and reset configuration
	puts(BY "MPU Accelerometer Measurement Started...\n" RESET); // Print start message
	
	tw_init(TW_FREQ_400K, true);     // Initialize TWI (I2C) with 400kHz frequency and internal pull-up resistors
	mpu_initialize();                // Initialize the MPU6050 sensor
	timer1_config();                 // Configure Timer1 for timing operations
	sei();                           // Enable global interrupts

	accel_t accel_data;              // Create a variable to store accelerometer data
	char time_buffer[20];            // Buffer to store the timestamp
	
	puts(BG CURSOR_RIGHT("14")
	"--------------- Application Running ---------------\n" RESET); // Print running message
	
	while (1)
	{
		if (read_flag)              // Check if the read_flag is set
		{
			read_flag = 0;         // Clear the read_flag
			convert_accel_data(&accel_data); // Convert raw accelerometer data to physical units
			
			// Print the accelerometer data
			printf("AX %5.2f ", accel_data.x_axis);
			printf("AY %5.2f ", accel_data.y_axis);
			printf("AZ %5.2f ", accel_data.z_axis);
			
			format_timestamp(time_buffer);  // Create a formatted timestamp
			printf("%s\n", time_buffer);    // Print the timestamp
		}
	}
}

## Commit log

2024-09-19 PCB Files
    Added PCB Files with all the Schematics and the Gerber Files.
    [EDR_SEM_4.PrjPcb, MCU.SchDoc, Main.SchDoc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]
2024-09-19 Enclosure Design
    Added the Enclosure Design solidworks files for both parts
    [Accelerometer.SLDPRT, Accelerometer_Base.SLDPRT, Accelerometer_Lid.SLDPRT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]
2024-09-19 Added test data files.
    Added some data files which captured before and after implementing the shock absorber.
    [after_shock.csv, before_shock.csv]
